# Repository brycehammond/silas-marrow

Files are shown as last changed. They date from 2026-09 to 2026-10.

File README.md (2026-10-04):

# Silas Marrow: the talking skull of the Elephant Corral

A life-size skull by the office door that turns to look at people, roasts their outfit in a raspy Old West voice, and talks back when they answer. The character is the (fictional) ghost of a faro dealer who has haunted the Elephant Corral at 1444 Wazee St since 1859. The history it uses is real, pulled from the building's historical markers.

```
 Anker C200 (in the base)
      │  video + mic
      ▼
 Mac mini ── skull.py ─────────────────────────────────────────────┐
   • YOLO pose tracking: where is the nearest face?                │
   • Claude (Sonnet 5.5): look at the frame, write a line           │
   • ElevenLabs Flash TTS: speak it; audio level drives the jaw     │
   • ElevenLabs Scribe STT: hear the reply, keep the conversation   │
   • Phone control page on port 8090                                │
      │ headphone jack                 │ USB serial                  │
      ▼                                ▼                             │
 PAM8403 amp ─► 40 mm speaker     Arduino Uno ─► jaw servo (MG90S)    │
 (under the jaw)                               ─► pan servo (MG996R)  │
                                               ─► tilt servo (MG996R) │
                                               ─► 2 x WS2812 eye jewels
```

## Folder map

| Path | What it is |
|---|---|
| `software/skull.py` | Main program: vision, behavior, web control page |
| `software/brain.py` | Claude prompts (greeting, conversation) |
| `software/voice.py` | ElevenLabs speech out with jaw sync, speech in |
| `software/vision.py` | Camera thread, YOLO pose tracking, gaze math |
| `software/faces.py` | Short-term face memory, so nobody is greeted twice |
| `software/hardware.py` | Serial link to the Arduino |
| `software/virtual.py` | Software twin of the Arduino sketch, for the on-screen skull |
| `software/web/` | The on-screen 3D skull (three.js) |
| `software/calibrate.py` | Servo, eye, mic and voice test tools |
| `software/persona.md` | Silas's character, history and rules. Edit freely. |
| `software/config.json` | All the tuning knobs |
| `firmware/skull_controller/` | Arduino sketch |
| `cad/skull_parts.scad` | Parametric source for every printed part |
| `cad/stl/` | Ready-to-print STLs (default measurements) |
| `cad/previews/` | Renders of the assembly and parts |
| `docs/parts.md` | Full parts list with quantities and specs |
| `docs/wiring.svg` | Wiring diagram |
| `docs/assembly.md` | Step-by-step assembly guide with a screw table |

## 1. Parts

The full list with quantities and specs is in [docs/parts.md](docs/parts.md). In short:

**Already in your cart:** Evotech skull, Hosyond MG996R 4-pack, Miuzei MG90S 4-pack, HiLetgo PAM8403 amp (with knob), Gikfun 40 mm 4Ω speakers, capacitor kit, lazy susan bearings, servo extension cables, ALITOVE 5V 5A supply, WS2812 7-LED jewels, speaker grille cloth.

**You have:** Mac mini, Anker PowerConf C200, Arduino Uno (a Nano works too), 3D printer.

**Small hardware to scrounge or grab at the hardware store:**

- M3 screws, 8 to 16 mm, about 30 (they self-tap into the printed pilot holes)
- One M5 x 50 mm bolt, nylon lock nut and 2 washers (idle tilt pivot)
- 1.5 mm steel wire for the jaw pushrod (music wire, or a big paperclip)
- 5-minute epoxy or E6000 (jaw tab, eye holders)
- Double-sided foam tape, small zip ties, hookup wire
- One 330Ω resistor (eye data line)
- A 5V USB wall charger and a spare USB cable to cut up (amp power)
- A 3.5 mm audio cable to cut up (Mac headphone jack to amp)

## 2. Printing

Default measurements match the parts you ordered. **Before printing, measure your actual parts** and edit the values marked `(M)` at the top of `cad/skull_parts.scad`. Then re-export with:

```bash
brew install --cask openscad@snapshot    # the stable cask is disabled in Homebrew
openscad -D 'part="turntable"' -o stl/turntable.stl skull_parts.scad
```

| Part | Qty | Material | Orientation / supports | Notes |
|---|---|---|---|---|
| `base_shell` | 1 | PLA, 3 walls, 15% infill | Top face on the bed (the STL is already flipped). No supports. | About 12 hr. Needs a 150 mm square bed area. |
| `base_floor` | 1 | PLA | Flat | Arduino standoffs, amp pad, camera cradle screws |
| `camera_cradle` | 1 | PLA | As exported, **supports on** under the shelf | Check `cam_w/h/d` against your Anker first |
| `grille_frame` | 1 | PLA, black | Lip on the bed | Clamps the grille cloth in the camera window |
| `turntable` | 1 | PETG preferred, 40% infill | Disc on the bed | Carries the whole head. Check `ls_size`, `ls_hole`. |
| `horn_column` | 1 | PETG | Standing up | Couples the pan servo horn to the turntable. Flat sides leave room for the wires. |
| `cradle` | 1 | PETG, 40% infill | Platform on the bed (already flipped) | The skull sits on this. Jaw servo mounts to it. |
| `pivot_spacer` | 1 | Any | Standing up | Goes on the M5 bolt |
| `speaker_holder` | 1 | PLA | Ring on the bed | |
| `jaw_tab` | 2 | PLA | Flat | One spare |
| `eye_holder` | 2 | PLA, black | Flat | |
| `eye_diffuser` | 2 | White or translucent PLA/PETG, 2 perimeters | Dome up | Frosts the LEDs into a glow |
| `pvc_socket` | 1 | PLA | Flange on the bed | Optional: mounts the base on a 2" PVC pipe column |

**Print order.** Start with the small parts that test your measurements, and leave the 12-hour `base_shell` for last:

1. `camera_cradle`, `speaker_holder` and both `eye_holder`s. They are quick, and each one checks a measured part (the camera, the speaker, the LED jewel). Fix the `(M)` values and re-export if anything is off.
2. Both `jaw_tab`s and both `eye_diffuser`s. With the eye holders, that is everything you need to prepare the skull, and the jaw tab's epoxy can cure while the big parts print.
3. `base_floor`. Check the camera cradle screw holes and the Arduino standoffs against it.
4. `grille_frame` and `pivot_spacer`, whenever they fit in. Batch the frame with the eye holders if you are swapping to black filament.
5. `base_shell`. It depends on the servo and lazy susan measurements too (the pan servo mount and the bearing slots), so check those once more before you commit to it.

The PETG neck parts (`turntable`, `horn_column`, `cradle`) are a separate batch. The neck cannot be assembled until they and the shell are done.

## 3. Wiring

Wiring diagram

The same connections as text:

```
                   ALITOVE 5V 5A ── screw adapter ──┬── + servo power rail
                                                    └── − servo power rail ─┐
  1000µF cap across + and − right at the rail (stripe to −)                 │
                                                                            │
  Arduino Uno                                                               │
    D9  ── jaw servo signal (orange)       servo red  ── + rail             │
    D10 ── pan servo signal                servo brown ── − rail            │
    D11 ── tilt servo signal                                                │
    D6  ──[330Ω]── eye jewel #1 DIN;  jewel #1 DOUT ── jewel #2 DIN          │
               jewels 5V ── + rail;  jewels GND ── − rail                   │
    GND ───────────────────────────────────────────────────────────────────┘
    USB ── Mac mini (data + Arduino power)

  Audio:  Mac mini headphone jack ── 3.5 mm cable ── PAM8403 L-in + GND
          PAM8403 L-out +/− ── 40 mm speaker     (never tie L− and R− together)
          PAM8403 5V/GND ── separate USB wall charger (keeps servo noise out)
          Put a 1000µF cap across the amp's 5V/GND pads.
```

Rules that prevent 90% of problems:

- **Common ground.** Arduino GND must connect to the servo supply's −. Otherwise the servos twitch randomly.
- **Never power servos from the Arduino's 5V pin.** The ALITOVE powers servos and eyes.
- **Keep the amp on its own USB charger.** Sharing the servo supply puts buzz in the voice.
- Run the skull's wires (jaw servo, eyes, speaker) down through the foramen magnum (the big hole in the skull base), through the cradle's center hole, the turntable's two cable openings beside the horn column, the lazy susan, and into the base. Leave a loose loop so the head can turn ±60°.

## 4. Assembly

The full guide, with a screw table, pictures and a bench test to do first, is in
[docs/assembly.md](docs/assembly.md). The short version:

**Skull prep**

1. Lift off the skull cap (it's held with magnets and pegs, so pull straight up).
2. Unhook the jaw spring. The servo drives the jaw now. If the jaw flops too freely, a much lighter rubber band can take the spring's place later.
3. Epoxy the `jaw_tab` to the inside of the chin, centered, with the ear pointing back toward the throat.
4. Press each LED jewel into an `eye_holder`, clip a `eye_diffuser` on the front, and epoxy the holders inside the eye sockets from within the cranium. Chain the jewels (DOUT of the first to DIN of the second) and route the three wires down through the foramen magnum.
5. Weather the skull if you like: raw umber acrylic, brushed on and wiped off, leaves "old bone" in the cracks.

**Neck**

6. Trim two opposite sides off the pan servo's round disc horn so it is 17 mm wide, the same as the flat-sided `horn_column`. Screw the horn to the bottom of the column with the flats lined up (radial slots fit most horns), then screw the column under the `turntable` with four countersunk M3s. The wires from the head pass down beside those flats.
7. Screw the lazy susan's top plate to the turntable, and its bottom plate to the top of the `base_shell` (the diagonal slots fit most hole patterns).
8. Hang the pan servo under the base top: shaft up into the horn, tabs screwed to the two bridges. Before pressing it onto the horn, center the servo (`python calibrate.py servos`, pick 1, press c) with the head facing forward.
9. Mount the tilt servo in the +X upright with its body outside and the spline poking through.
10. Mount the MG90S jaw servo in the cradle's front plate, and the speaker in the `speaker_holder`, screwed to the cradle's front edge.
11. Screw the `cradle` to the skull base with M3s through the long slots. **Don't tighten yet.**
12. Hang the cradle in the yoke: servo horn screwed to the +X arm, M5 bolt through the −X upright, spacer and arm.
13. **Balance.** With the tilt servo relaxed (`X` command or unplugged), slide the skull forward or back in the slots until it barely tips either way. Then tighten. A balanced head is what lets the MG996R hold it steadily all day.
14. Bend a Z in one end of the 1.5 mm wire, hook it in the jaw tab, and connect the other end to the jaw servo horn. With the servo at closed, size the wire so the jaw is just shut.

**Base**

15. Screw the Arduino to the standoffs on the `base_floor`, stick the amp on its pad with foam tape, and screw the `camera_cradle` in behind the window.
16. Strap the Anker into the cradle with zip ties. Its lens should sit right against the window.
17. Stretch grille cloth over the window and press the `grille_frame` in from outside to clamp it tight.
18. Screw the floor to the shell. Optional: bolt on the `pvc_socket` and stand the whole thing on a 2" PVC pipe so the skull is at eye level.

## 5. Mac mini setup

```bash
brew install python@3.12 ffmpeg
cd talking-skull/software
python3.12 -m venv .venv && source .venv/bin/activate
pip install -r requirements.txt
cp .env.example .env        # paste your Anthropic and ElevenLabs keys in
```

**Voice.** `config.json` uses **Jessie, Vintage Narrator** (`KgUSWQPFmuiZ5ycRbnty`), a raspy Wild West old-timer from the ElevenLabs voice library. Library voices need to be added to your account before the API can use them: in ElevenLabs, open Voice Library, search "Jessie Vintage Narrator", and click Add to my voices. Two other good fits:

- `uVKHymY7OYMd6OailpG5`: Frederick, Old Gnarly Narrator (deep, grizzled)
- `1BfrkuYXmEwp8AWqSLWk`: Declan Graves (creepier, slight Irish rasp)

**Devices.**

```bash
python skull.py --list-cameras     # set camera.index
python skull.py --list-audio       # set voice.output_device and ears.input_device (name fragments)
ls /dev/cu.usbmodem*               # set hardware.serial_port
```

Give Terminal camera and microphone access when macOS asks (System Settings > Privacy & Security).

**Firmware.** In the Arduino IDE, install **Adafruit NeoPixel** from the Library Manager, open `firmware/skull_controller/skull_controller.ino`, and upload to the Uno.

## 6. Calibration

1. **Servo limits.** Take the skull off first. Run `python calibrate.py servos`. For each servo, find the pulse for jaw closed and open, pan center and a comfortable left limit, and tilt level and a comfortable up limit. Put the numbers in the calibration block at the top of the sketch and upload again. Flip the sign of `PAN_SPAN_US` or `TILT_SPAN_US` if an axis runs backwards.
2. **Eyes.** `python calibrate.py eyes` cycles colors and modes. Pick a color on the phone page later.
3. **Voice and jaw.** `python calibrate.py say "Howdy, pilgrim."`. If the jaw flaps at silence, raise `jaw_floor_db`. If it barely moves, lower `jaw_ceiling_db`. If it runs ahead of or behind the audio, adjust `jaw_delay_s` by ±0.05.
4. **Mic.** `python calibrate.py mic`. Talk from where people stand and set `ears.speech_min_rms` a bit above the room-noise reading.
5. **Gaze.** `python skull.py --show`, stand in front, and move around. If the head aims low (the camera sits below the eyes), raise `gaze.tilt_offset_deg`. If it turns the wrong way, set `invert_pan` or `invert_tilt`. If it under- or over-turns, adjust `pan_range_deg` and `tilt_range_deg` to match the angles your servo spans reach.

## 7. Running it

```bash
python skull.py --show --no-skull    # first test: camera + Claude + voice, no Arduino
python skull.py --show               # everything, with a preview window
python skull.py                      # headless; use the phone page
```

Open `http://<mac-mini-name>.local:8090` on your phone. The page has:

- a live camera view
- **Arm** (it starts armed; set `start_armed` to `false` in `config.json` to change that) and **Conversation** toggles
- **Greet now**, **Stop talking**, **Center head** and **Relax servos** buttons
- a **Say** box, so you can puppet Silas live
- volume and eye color controls
- a log of everything it said and heard

Set `web.token` to require `?t=yourtoken` on the URL.

### Virtual skull

No hardware on the desk? Silas can live on the screen instead:

```bash
python skull.py --virtual                        # everything, with an on-screen skull
python skull.py --virtual --no-voice --no-ai     # no API keys needed
```

`--virtual` replaces the Arduino with a 3D skull in its own window. Everything else is
the real thing: it watches through this computer's camera, listens on its microphone,
talks through its speakers, and greets and converses by the same rules. It starts armed,
and you can disarm it from the control page as usual.

- **Devices.** With `--virtual`, the `camera`, `ears`, `voice` and `gaze` values inside
  the `virtual` section of `config.json` replace the main ones. `null` for a device means
  the system default, which is normally the built-in microphone and speakers. The Mac
  mini settings are left alone. The virtual camera is picked by name
  (`virtual.camera.name`, "MacBook Pro Camera"), because an iPhone nearby can take
  index 0. `--list-cameras` shows each camera's index and name. Change the name if your
  Mac's camera is called something else. With no match it falls back to `index`.
- **Permissions.** macOS asks for Camera and Microphone access for the terminal you
  run it from.
- **Window.** It opens in Google Chrome's app mode if Chrome is installed, otherwise in
  your default browser. Set `virtual.open_window` to `false` to open it yourself at
  `http://localhost:8090/skull`. Keys: **F** full screen, **C** camera picture,
  **H** hide the text.
- **Gaze.** A webcam sits above the screen, not under the skull. If Silas looks over your
  head or at your chest, change `virtual.gaze.tilt_offset_deg`. If he turns the wrong way
  (a mirrored camera), set `virtual.invert_pan`.
- **Same behavior as the hardware.** The on-screen skull obeys the same commands as the
  Arduino, with the same head smoothing, jaw timeout and eye modes. It also runs next to
  the real skull: open `/skull` on any device to watch a live twin.
- **Without a voice** (`--no-voice`) the jaw still moves for each line, so you can see
  him talk.
- **A better looking skull.** The built-in skull is generated by code and is stylized.
  To use a sculpted one, save it as `software/web/skull.glb` with these named parts:
  `cranium`, `jaw` (its origin on the jaw hinge), and empties `eye_L` and `eye_R` in the
  sockets. Face it toward +Z with Y up, with the jaw's local X axis along the hinge
  (in Blender: face it toward -Y, leave the jaw unrotated, and export glTF with +Y up).
  Any size works. Restart `skull.py` after adding the file.

**How it behaves.** When an armed skull sees a face close enough (`min_height_frac`) for `present_s`, it greets that person once and waits at least `min_gap_s` between greetings. It remembers each face it has greeted and leaves that person alone for 4 hours (`regreet_same_person_after_s`), even if they leave and come back. The exception: someone already greeted who stops and looks at it for 10 seconds (`linger_s`) gets another line, at most once every 5 minutes (`linger_gap_s`). It needs about a second of clear, front-on view before it greets, so it can tell who it is looking at. Set `greet_unrecognized` to `true` to greet people whose face it can't make out, or `recognize_faces` to `false` to go back to tracking alone. With conversation on, it listens for up to 5 seconds after each line and keeps talking for up to 4 turns, or until the person walks away. It only runs during `active_hours` (7am to 7pm by default), and `ambient_every_min` can make it mutter to itself when the hall is empty (off by default).

**Keep it running.** Use `caffeinate -dimsu &`, or a launchd job like the one in the spider README.

**Costs (rough).** A greeting sends one downscaled frame plus the persona to Claude Sonnet 5.5: about 2,000 input tokens. On Haiku 4.5 that came to around $0.25 for 100 greetings a day. Sonnet costs more, so check Anthropic's current pricing. ElevenLabs is the bigger cost. Each line is about 100 to 150 characters, and Flash models bill around half a credit per character, so check that your plan's monthly credits cover a busy month. `max_greetings_per_hour` is your cost cap.

## 8. Make it yours

- **Personality and history:** edit `software/persona.md`. It is plain text, and the program re-reads it on start.
- **Cheaper replies:** set `claude.model` to `claude-haiku-4-5-20251001` and delete the `claude.thinking` line. Haiku rejects that setting. Sonnet 5.5 needs it: without `"thinking": "between_tools"` it spends the whole token budget thinking and returns an empty line.
- **More expressive voice:** set `voice.tts_model` to `eleven_v3` and `claude.allow_audio_tags` to `true`. Silas can then `[chuckles]` and `[whispers]`, at the cost of more latency.

## 9. Privacy and etiquette

Camera frames are sent to Anthropic's API only at the moment of a greeting. Speech is sent to ElevenLabs only while the skull is listening. Nothing is saved to disk. The persona forbids comments on bodies, age, race and the like, and it has to admit it's an AI if someone sincerely asks.

## 10. Troubleshooting

| Symptom | Fix |
|---|---|
| Servos twitch or the Arduino resets | Common ground missing, supply too weak, or the 1000µF cap is missing |
| Head drifts to center on its own | The Mac stopped sending (watchdog). Check the serial port. |
| Jaw doesn't move while talking | `jaw_floor_db` is too high, or the pushrod is binding. Test with `calibrate.py say`. |
| Voice buzzes or hums | Amp on its own USB charger. Add the cap. Try a ground loop isolator. |
| `ElevenLabs TTS 401/403` | The key is wrong, or the voice isn't added to your account |
| PCM refused | The code falls back to MP3 automatically (needs `brew install ffmpeg`) |
| It greets the same person over and over | Lower `face_match_threshold` a little (0.30) so faces match more easily, and raise `linger_gap_s` |
| It ignores a new person | Raise `face_match_threshold` (0.45). It may be taking them for someone it already greeted. |
| It never greets | Check that it's armed, inside active hours, and that `min_height_frac` isn't too high for your hallway. It also waits for a clear, front-on face unless `greet_unrecognized` is `true`. |
| Virtual skull page says "offline" | `skull.py` is not running, or the `?t=` token is missing from the URL |
| Virtual skull hears nothing | Microphone access for the terminal, and `virtual.ears.input_device` (`null` = system default) |

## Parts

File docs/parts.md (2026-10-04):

# Parts list

Everything needed to build the physical skull. Wiring is in [wiring.svg](wiring.svg),
assembly is in [assembly.md](assembly.md), and print settings are in the
[README](../README.md).

Brands are the ones used in this build. Any part that matches the spec will work, but
check the printed parts against it first: the dimensions marked `(M)` in
`cad/skull_parts.scad` were measured from these exact parts. Prices and shop links are
left out because they go stale.

The on-screen skull (`python skull.py --virtual`) needs none of this, only a Mac with a
camera and a microphone.

## Electronics

| Part | Qty | Spec | Used in this build | Job |
|---|---|---|---|---|
| Arduino Uno | 1 | A Nano also works | | Drives the servos and eyes |
| Standard servo | 2 | MG996R, metal gear | Hosyond, sold as a 4-pack | Pan and tilt |
| Micro servo | 1 | MG90S, metal gear | Miuzei, sold as a 4-pack | Jaw |
| LED jewel | 2 | WS2812, 7 LEDs, 23 mm across | | Eyes |
| Power supply | 1 | 5 V, 5 A, with a barrel to screw terminal adapter | ALITOVE | Servos and eyes |
| Electrolytic capacitor | 2 | 1000 µF, rated 10 V or more | From a capacitor kit | One across the servo power rail, one across the amp's power pads |
| Resistor | 1 | 330 Ω | | In series with the eye data line |
| Amplifier board | 1 | PAM8403, with volume knob | HiLetgo | Drives the speaker |
| Speaker | 1 | 40 mm, 4 Ω | Gikfun | Voice, mounted under the jaw |
| Servo extension cable | up to 3 | One per servo that cannot reach the Arduino | | Runs from the head down into the base |
| USB wall charger | 1 | 5 V | | Powers the amp only |
| USB cable | 1 | Any spare one, to cut up | | Charger to amp |
| Audio cable | 1 | 3.5 mm, to cut up | | Headphone jack to amp |
| USB cable for the Arduino | 1 | Type B for an Uno | | Arduino to computer |
| Hookup wire | some | | | Power rail, eyes, speaker |

The 10 V rating on the capacitors is a recommendation added here. The README only gives
the capacitance.

## Computer, camera and microphone

| Part | Qty | Used in this build | Job |
|---|---|---|---|
| Computer | 1 | Mac mini | Runs `skull.py` |
| Webcam with microphone | 1 | Anker PowerConf C200, 40.8 x 50.6 x 55.1 mm with the clip folded | Sees and hears visitors |

## Mechanical

| Part | Qty | Spec | Job |
|---|---|---|---|
| Life-size plastic skull | 1 | Hinged jaw, removable cap. This build uses an Evotech skull. | Silas |
| Lazy susan bearing | 1 | Sold as 3 in. The plates measure 72 mm square, 9 mm tall, with a 35.3 mm center opening. | Carries the head on the base |
| M3 screws | about 30 | 8 to 16 mm long | Self-tap into the printed pilot holes |
| M5 bolt | 1 | 50 mm long | Idle tilt pivot |
| M5 nylon lock nut | 1 | | Idle tilt pivot |
| M5 washer | 2 | | Idle tilt pivot |
| Machine screws with nuts and washers | about 8 | Short, M3 or M4 to suit the bearing's holes | Lazy susan plates to the turntable and base. Not in the README. See the assembly guide. |
| Steel wire | 1 short length | 1.5 mm music wire, or a large paperclip | Jaw pushrod |
| Speaker grille cloth | 1 piece | Big enough to cover the camera window | Hides the camera |
| PVC pipe | 1, optional | 2 in | Stands the skull at eye level |

## Printed parts

Material, orientation and supports are in section 2 of the README.

| Part | Qty | Material |
|---|---|---|
| `base_shell` | 1 | PLA |
| `base_floor` | 1 | PLA |
| `camera_cradle` | 1 | PLA |
| `grille_frame` | 1 | PLA, black |
| `turntable` | 1 | PETG preferred |
| `horn_column` | 1 | PETG |
| `cradle` | 1 | PETG |
| `pivot_spacer` | 1 | Any |
| `speaker_holder` | 1 | PLA |
| `jaw_tab` | 2 | PLA. One is a spare. |
| `eye_holder` | 2 | PLA, black |
| `eye_diffuser` | 2 | White or translucent PLA or PETG |
| `pvc_socket` | 1, optional | PLA |

## Consumables

| Item | Job |
|---|---|
| 5-minute epoxy or E6000 | Jaw tab and eye holders |
| Double-sided foam tape | Holds the amp on its pad |
| Small zip ties | Straps the camera into its cradle |
| Raw umber acrylic paint, optional | Weathers the skull |

## Tools

| Tool | Why |
|---|---|
| 3D printer | Needs a 150 mm square bed area for `base_shell` |
| Soldering iron | The LED jewels have solder pads, and the cut audio and USB cables need joining |
| Arduino IDE | Uploads the firmware. Needs the Adafruit NeoPixel library. |

## What is left over

The servos are sold in packs of four. This build uses two MG996R and one MG90S, which
leaves two and three spare.

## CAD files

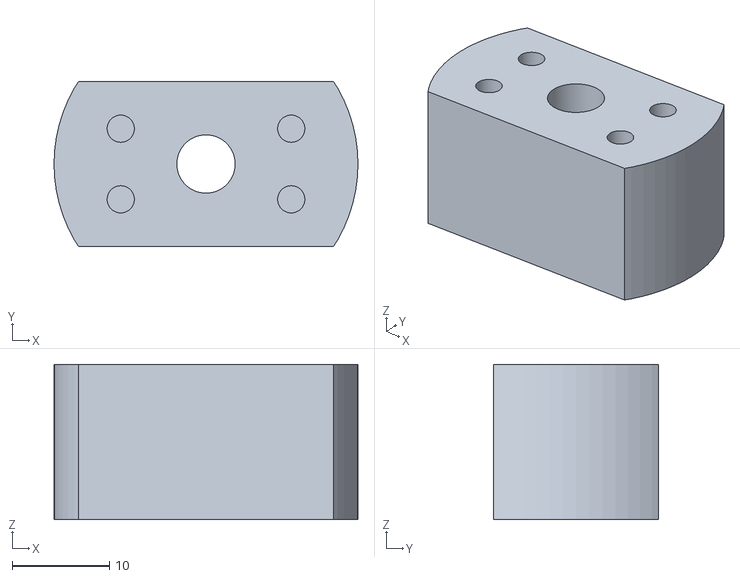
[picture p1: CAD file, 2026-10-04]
cad/stl/horn_column.stl
31.3 x 17.0 x 16.0

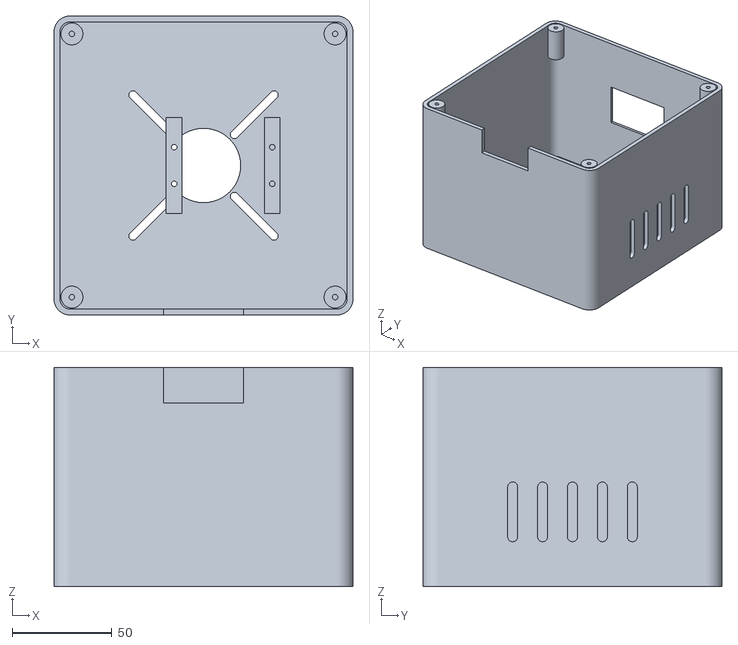
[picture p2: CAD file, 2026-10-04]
cad/stl/base_shell.stl
150.0 x 150.0 x 110.0

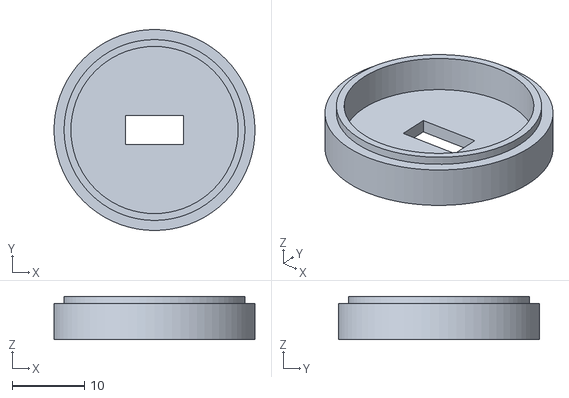
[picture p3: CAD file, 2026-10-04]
cad/stl/eye_holder.stl
27.9 x 27.9 x 6.00

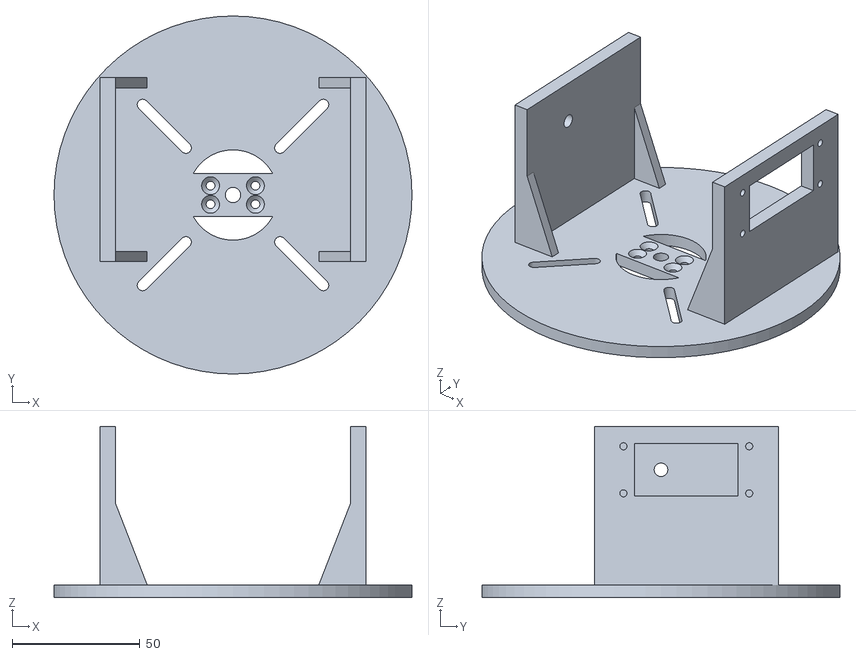
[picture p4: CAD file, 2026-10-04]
cad/stl/turntable.stl
140.0 x 140.0 x 67.0

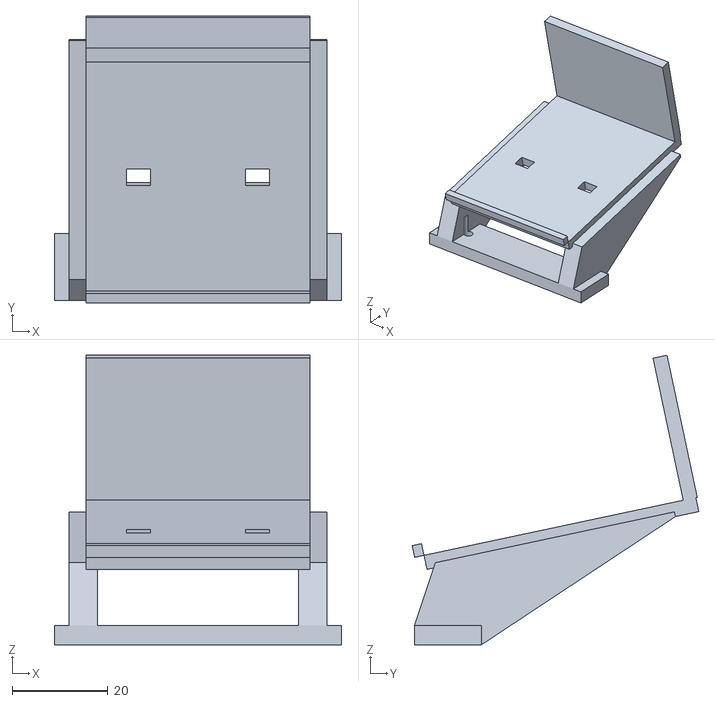
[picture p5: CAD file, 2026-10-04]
cad/stl/camera_cradle.stl
60.0 x 59.9 x 60.5

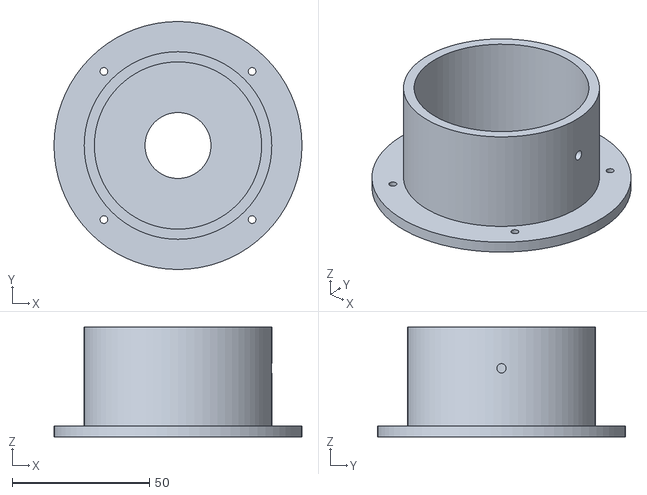
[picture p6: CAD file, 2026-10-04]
cad/stl/pvc_socket.stl
90.3 x 90.3 x 40.0

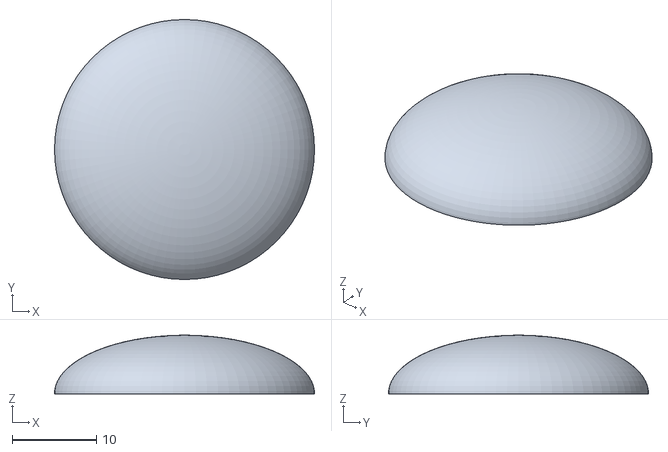
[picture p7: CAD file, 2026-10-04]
cad/stl/eye_diffuser.stl
30.9 x 30.9 x 6.95

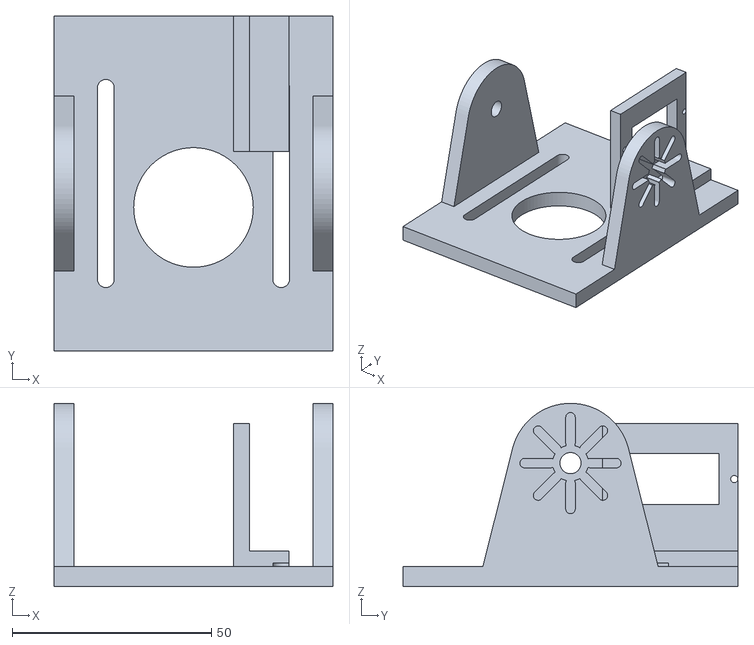
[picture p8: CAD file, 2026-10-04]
cad/stl/cradle.stl
70.0 x 84.0 x 46.0

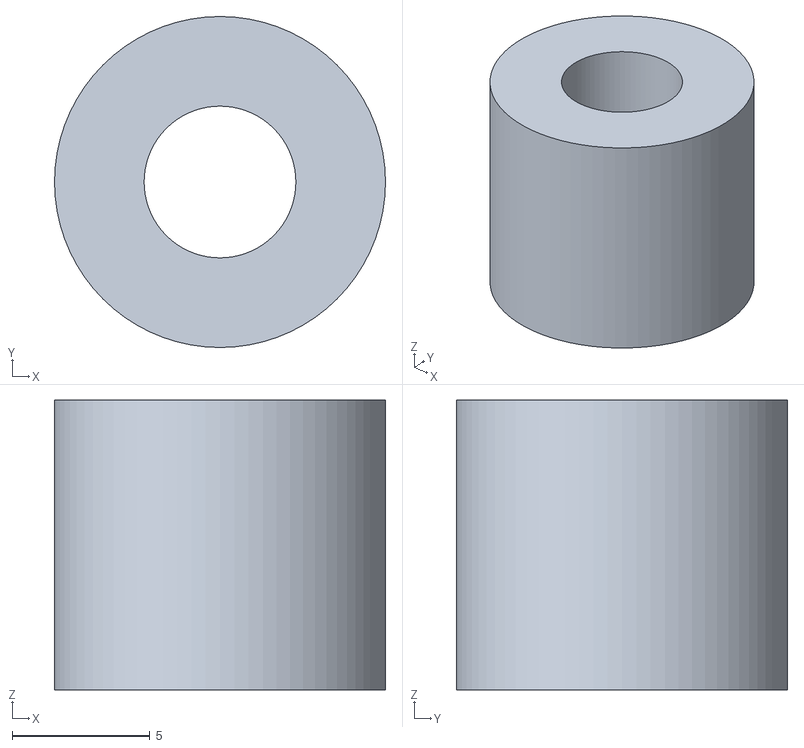
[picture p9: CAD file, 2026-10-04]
cad/stl/pivot_spacer.stl
12.0 x 12.0 x 10.5

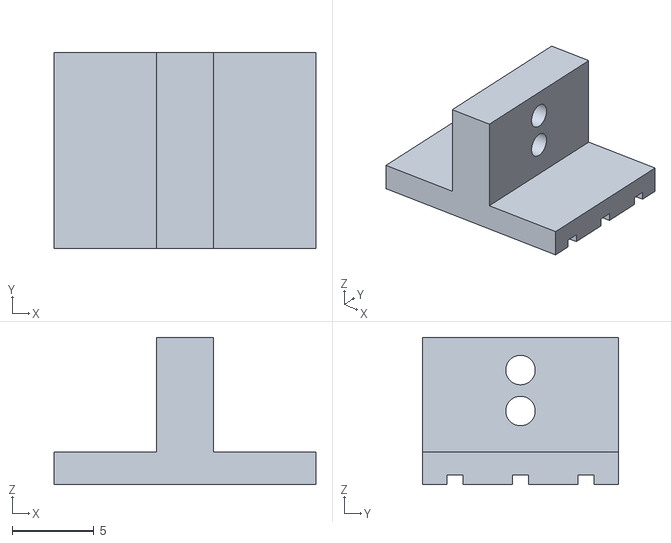
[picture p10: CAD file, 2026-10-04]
cad/stl/jaw_tab.stl
16.0 x 12.0 x 9.00

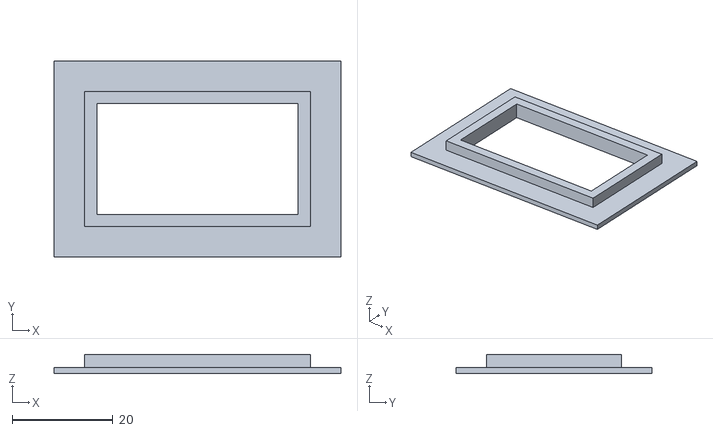
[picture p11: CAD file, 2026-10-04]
cad/stl/grille_frame.stl
57.0 x 39.0 x 3.79

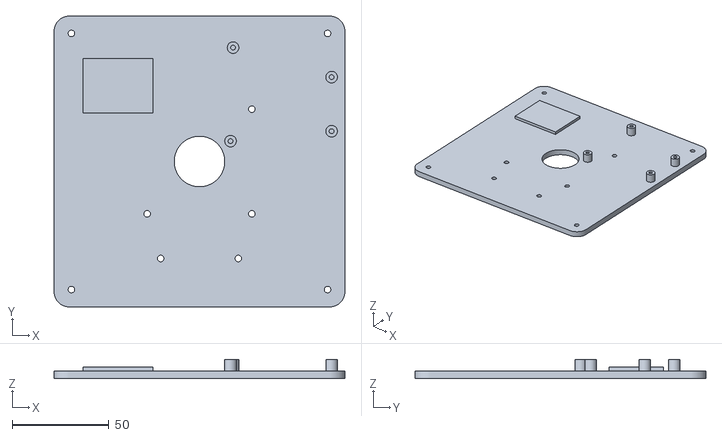
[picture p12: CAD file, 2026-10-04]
cad/stl/base_floor.stl
150.0 x 150.0 x 10.0

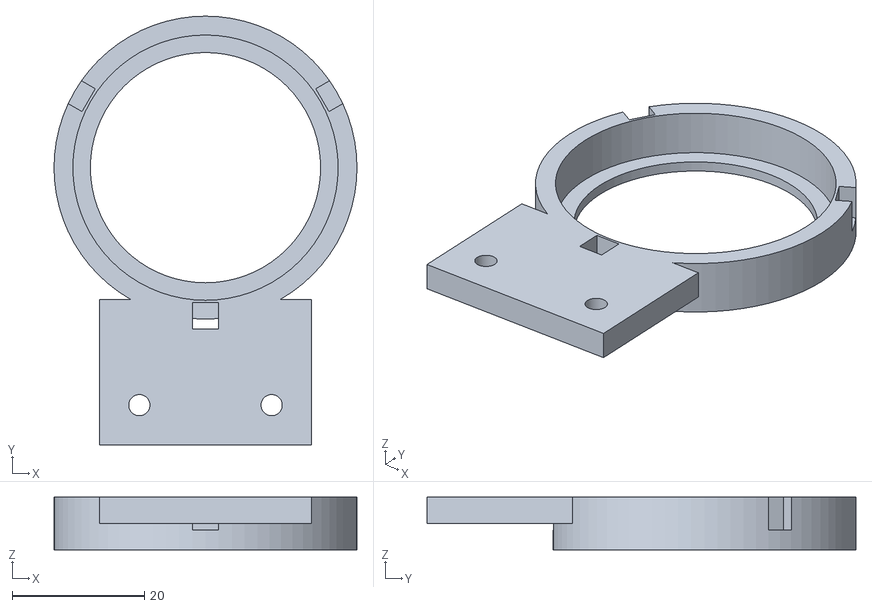
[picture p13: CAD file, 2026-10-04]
cad/stl/speaker_holder.stl
45.8 x 64.8 x 8.00

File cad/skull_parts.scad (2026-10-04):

// ===========================================================================
// Talking skull: printable parts (parametric OpenSCAD)
//
// Render one part:   openscad -D 'part="turntable"' -o turntable.stl skull_parts.scad
// Preview assembly:  open this file in OpenSCAD with part="assembly"
//
// MEASURE YOUR PARTS and edit the values marked (M) before printing.
// Units: millimeters. Front of the prop is -Y (toward the people).
// ===========================================================================

part = "assembly";   // see the list at the bottom of this file
$fn = 72;
eps = 0.01;
tol = 0.3;           // general printing clearance

// ---------------- base (pedestal) ----------------
base_w = 150;  base_d = 150;  base_h = 110;
wall = 3;      top_t = 5;     corner_r = 8;
floor_t = 4;

// ---------------- lazy susan (sold as 3 in, plates measure 72 mm) ----------------
ls_size = 72;      // (M) plate size
ls_h = 9;            // (M) total height of the bearing, plate to plate
ls_hole = 35.3;        // (M) diameter of the lazy susan's center opening
ls_slot_r0 = 22;     // slots along the diagonals from r0 to r1 fit most hole patterns
ls_slot_r1 = 50;

// ---------------- MG996R (neck servos) ----------------
s_L = 40;          // (M) body length
s_W = 20;          // (M) body width
s_tab_under = 32.2;  // (M) bottom of case to underside of the mounting tabs
s_tab_t = 2.4;
s_spline_top = 46.4; // (M) bottom of case to top of output spline
s_shaft_off = 10.1;  // (M) end of case to shaft center
s_hole_L = 49.2;     // (M) tab hole spacing along length
s_hole_W = 18.4;       // (M) tab hole spacing across width
s_pilot = 2.8;       // self-tapping M3 into plastic
horn_d = 20.5;         // (M) round disc horn diameter
horn_t = 2.3;          // (M) horn disc thickness above the spline

// ---------------- MG90S (jaw servo) ----------------
j_L = 22.7;  j_W = 12.2;  j_tab_under = 17.8;  j_tab_t = 2.5;
j_spline_top = 32.4;  j_shaft_off = 6.0;  j_hole_L = 30.9;  j_pilot = 1.8;

// ---------------- neck geometry ----------------
tt_d = 140;          // turntable disc diameter
tt_t = 5;
column_d = ls_hole - 4;
column_w = 17;       // the column is flattened to this width so the cables pass either side
col_screw_a = [22.5, 157.5, 202.5, 337.5];   // column screws: between the horn slots
pivot_h = 45;        // tilt axis height above the turntable top
up_t = 6;            // upright thickness
up_w = 72;           // upright width (along Y), offset to cover the servo tabs
cr_w = 70;           // cradle platform width (X)
cr_d = 84;           // cradle platform depth (Y)
cr_t = 5;
arm_t = 5;
arm_drop = 26;       // platform underside to pivot axis
horn_gap = 11;       // upright inner face to cradle arm (fits spline + horn)
pivot_bolt = 5.3;    // M5 bolt for the idle side

// ---------------- camera + window ----------------
cam_w = 40.8;          // (M) Anker C200 width
cam_h = 50.6;          // (M) height
cam_d = 55.1;          // (M) depth front to back, clip folded
cam_tilt = 12;       // degrees upward
win_w = 46;  win_h = 28;
win_z = 48;          // window center height above the bottom of the base

// ---------------- electronics ----------------
uno_holes = [[14, 2.5], [15.3, 50.7], [66.1, 7.6], [66.1, 35.5]];
pvc_od = 60.3;       // 2 in schedule 40 PVC pipe

// ===========================================================================
// helpers
// ===========================================================================
module rbox(w, d, h, r) {
    hull() for (x = [-w/2 + r, w/2 - r], y = [-d/2 + r, d/2 - r])
        translate([x, y, 0]) cylinder(r = r, h = h);
}

module slot(len, w, h) {   // along +X from origin
    hull() { cylinder(d = w, h = h); translate([len, 0, 0]) cylinder(d = w, h = h); }
}

module diag_slots(r0, r1, w, h) {
    for (a = [45, 135, 225, 315]) rotate(a) translate([r0, 0, 0]) slot(r1 - r0, w, h);
}

module horn_slots(h, angles = [0 : 45 : 315], len = 6.5) {   // radial slots that fit most disc horns
    for (a = angles) rotate(a) translate([5, 0, 0]) slot(len, 2.4, h);
}

// Footprint shared by the horn column and the middle of the turntable: a round
// column with two flats. The wires from the head run down past the flats,
// inside the lazy susan's center opening.
module column_profile(h) {
    intersection() {
        cylinder(d = column_d, h = h);
        translate([-column_d/2, -column_w/2, 0]) cube([column_d, column_w, h]);
    }
}

module cable_channels(h) {   // the two openings either side of the column
    difference() {
        cylinder(d = ls_hole, h = h);
        translate([-ls_hole/2 - 1, -column_w/2, -1]) cube([ls_hole + 2, column_w, h + 2]);
    }
}

// ===========================================================================
// 1. base shell: hollow pedestal. Print upside down (top face on the bed).
// ===========================================================================
z_hc = base_h - top_t - 2;               // horn disc top under the top plate
s_spline_z = z_hc - horn_t;
s_tab_top_z = s_spline_z - (s_spline_top - s_tab_under - s_tab_t);
s_center_x = s_L/2 - s_shaft_off;        // servo body center relative to shaft

module base_shell() {
    difference() {
        union() {
            difference() {
                rbox(base_w, base_d, base_h, corner_r);
                translate([0, 0, -eps]) rbox(base_w - 2*wall, base_d - 2*wall,
                                             base_h - top_t, corner_r - wall);
            }
            // corner bosses for the floor screws
            for (x = [-1, 1], y = [-1, 1])
                translate([x * (base_w/2 - 9), y * (base_d/2 - 9), 0])
                    cylinder(d = 11, h = 22);
            // pan servo bridges: bars under the tab holes, legs out past the horn
            for (hx = [s_center_x - s_hole_L/2, s_center_x + s_hole_L/2]) {
                translate([hx - 4, -24, s_tab_top_z]) cube([8, 48, 5]);
                for (y = [-24, 18])
                    translate([hx - 4, y, s_tab_top_z]) cube([8, 6, base_h - top_t - s_tab_top_z + eps]);
            }
        }
        // floor screw pilots
        for (x = [-1, 1], y = [-1, 1])
            translate([x * (base_w/2 - 9), y * (base_d/2 - 9), -eps]) cylinder(d = s_pilot, h = 18);
        // servo tab pilots (drilled up into the bridges)
        for (hx = [s_center_x - s_hole_L/2, s_center_x + s_hole_L/2], y = [-s_hole_W/2, s_hole_W/2])
            translate([hx, y, s_tab_top_z - eps]) cylinder(d = s_pilot, h = 5 + 2*eps);
        // clearance for the servo body between the bridges
        translate([s_center_x - s_L/2 - tol, -s_W/2 - tol, s_tab_top_z - 1])
            cube([s_L + 2*tol, s_W + 2*tol, base_h - top_t - s_tab_top_z + 1 - eps]);
        // center opening for the turntable column
        translate([0, 0, base_h - top_t - 1]) cylinder(d = column_d + 6, h = top_t + 2);
        // lazy susan screw slots
        translate([0, 0, base_h - top_t - 1]) diag_slots(ls_slot_r0, ls_slot_r1, 4.2, top_t + 2);
        // camera window + recess for the grille frame lip
        translate([-win_w/2, -base_d/2 - 1, win_z - win_h/2]) cube([win_w, wall + 2, win_h]);
        translate([-(win_w + 12)/2, -base_d/2 - 1, win_z - (win_h + 12)/2])
            cube([win_w + 12, 1 + 1.2, win_h + 12]);
        // rear cable exit
        translate([-20, base_d/2 - wall - 1, -eps]) cube([40, wall + 2, 18]);
        // side vents
        for (s = [-1, 1], i = [0 : 4])
            translate([s * base_w/2 - wall, -30 + i * 15, 60]) rotate([0, 90, 0])
                translate([0, 0, -1]) hull() { cylinder(d = 5, h = wall + 2);
                    translate([-25, 0, 0]) cylinder(d = 5, h = wall + 2); }
    }
}

// ===========================================================================
// 2. base floor: screws under the shell, carries the Arduino, amp and camera.
// ===========================================================================
uno_origin = [2, 8];    // board corner position on the floor (rear right area)
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

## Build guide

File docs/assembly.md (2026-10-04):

# Assembly guide

How to put the physical skull together, from a pile of parts to a talking head.
Allow an afternoon once everything is printed.

- Parts and quantities: [parts.md](parts.md)
- Wiring: [wiring.svg](wiring.svg)
- Print settings, calibration and troubleshooting: [README](../README.md)

The steps follow the README. The screw sizes, hole counts and clearances were worked out
from the hole sizes in `cad/skull_parts.scad`. Nothing here has been checked against a
finished build yet, so read [Open questions](#open-questions) before you start.

If you printed the `turntable` or `horn_column` before the cable path was fixed, print
them again. The old ones have round cable holes and a fully round column, and the
wires cannot get through.

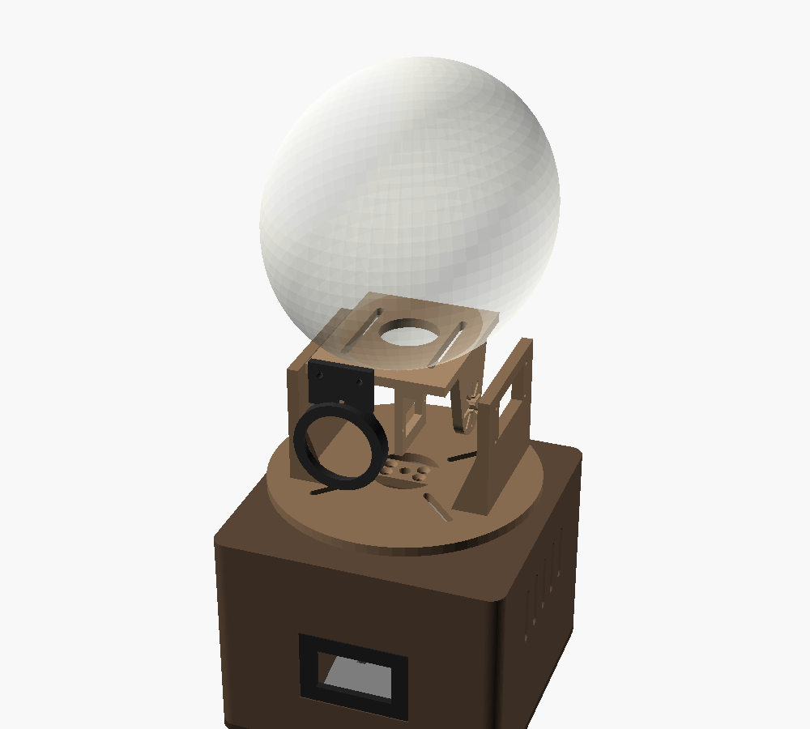
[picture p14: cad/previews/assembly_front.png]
The assembled neck and base


## Words used in this guide

| Word | Meaning |
|---|---|
| Front | The side of the base with the camera window. It faces the visitors. |
| Right upright | The turntable upright with the rectangular servo cutout. It is on your right when you face the front. The CAD calls it +X. |
| Left upright | The turntable upright with the single round bolt hole. The CAD calls it -X. |
| Horn | The plastic disc or arm that pushes onto a servo's output shaft. |

## Screws

All M3 screws self-tap into printed pilot holes. Drive them slowly and stop when they
are snug. A stripped hole in plastic does not recover.

| Where | Qty | Screw | Notes |
|---|---|---|---|
| Arduino to floor standoffs | 4 | M3 x 8 | |
| Camera cradle to floor | 2 | M3 x 10 or 12, countersunk | From under the floor |
| Pan servo to base bridges | 4 | M3 x 8 | Up through the servo tabs |
| Horn column to turntable | 4 | M3 x 12, countersunk | Down from the top of the turntable |
| Tilt servo to right upright | 4 | M3 x 8 | Through the servo tabs |
| Speaker holder to cradle | 2 | M3 x 10 or 12 | Into the cradle's front edge |
| Cradle to skull | 2 | M3 x 12 to 16, with washers | Through the long slots |
| Floor to shell | 4 | M3 x 12 to 16, countersunk | Into the corner posts |
| PVC socket to floor, optional | 4 | M3 x 10 or 12 | Plus one through the side hole to pin the pipe |
| Jaw servo to cradle | 2 | The small screws supplied with the MG90S | |
| Tilt pivot | 1 | M5 x 50 bolt, 2 washers, nylon lock nut | |

That is 26 M3 screws, or 31 with the PVC socket.

## Stage 1: test everything on the bench

Do this before any part is mounted. A servo that is centered now saves taking the neck
apart later.

1. Upload the firmware to the Arduino. The README covers this in section 5.
2. Wire the three servos, the two eye jewels and the power supply on the bench,
   following the [wiring diagram](wiring.svg). Leave the horns off the servos.
3. Run `python calibrate.py servos` from the `software` folder.
4. For each servo, pick it with `0`, `1` or `2` and press `c` to center it.
5. Mark the pan and tilt servo shafts with a dot of paint so you can see the center
   position later.
6. Run `python calibrate.py eyes` and check that both jewels light.
7. Wire the amp and speaker, then run `python calibrate.py say "Howdy."` and check for
   sound.
8. Unplug everything. Keep the servos at their centered positions.

## Stage 2: prepare the skull

1. Lift off the skull cap. It is held by magnets and pegs, so pull straight up.
2. Unhook the jaw spring. The servo drives the jaw now. If the jaw later flops too
   freely, fit a much lighter rubber band in the spring's place.
3. Epoxy one `jaw_tab` to the inside of the chin. Center it, with the upright fin
   pointing back toward the throat. The grooved face is the glue face.
4. Press each LED jewel into an `eye_holder`, with the wires leaving through the slot in
   the back.
5. Clip an `eye_diffuser` onto the front of each holder.
6. Chain the jewels: the first jewel's DOUT goes to the second jewel's DIN. Join the 5V
   pads together and the GND pads together.
7. Epoxy the holders inside the eye sockets, working from inside the cranium.
8. Route the three eye wires down through the large hole in the skull base.
9. Optional: brush raw umber acrylic onto the skull and wipe it off. It leaves old bone
   color in the cracks.

Let the epoxy cure fully before hanging any weight on the jaw tab.

## Stage 3: build the neck

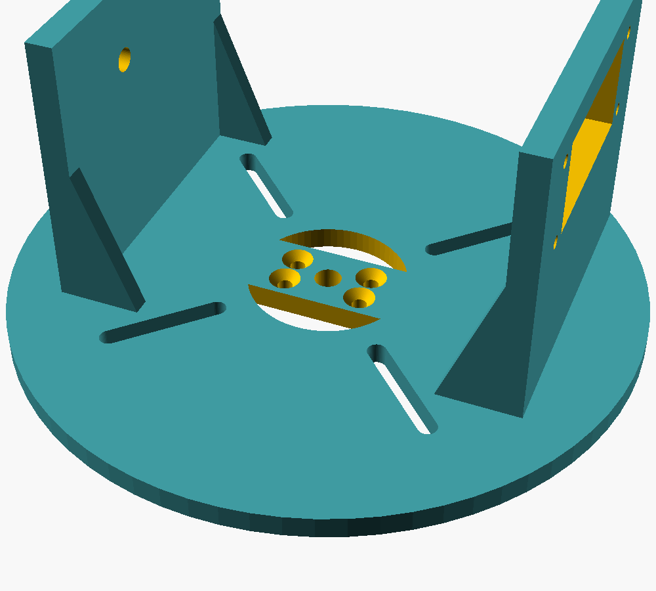
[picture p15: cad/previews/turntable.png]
The turntable


The `horn_column` has two flat sides. The wires from the head run down past those
flats, so nothing may stick out beyond them.

1. Trim two opposite sides off the pan servo's round disc horn until it is 17 mm wide,
   the same as the column. The horn is 20.5 mm across, so that is a little under 2 mm
   off each side. Side cutters and a file will do it. An untrimmed horn blocks
   the wires.
2. Screw the horn to the bottom of the column, with its trimmed sides in line with the
   flats. The bottom is the end with the slots and the wide recess. The two slots that
   run along the column are full length. The four diagonal ones are short.
3. Set the column under the center of the `turntable`, flats in line with the two
   curved openings, and fix it with four countersunk M3 screws from above.
4. Fasten the lazy susan's top plate to the underside of the turntable, through the
   diagonal slots.
5. Fasten the lazy susan's bottom plate to the top of the `base_shell`, through its
   diagonal slots. The column drops through the center opening.
6. Spin the turntable by hand. It must turn freely with no rubbing on the column.
7. Look down through each curved opening. You should see straight into the base.

Steps 4 and 5 need fasteners that the README does not list. See
[Open questions](#open-questions).

### Fit the pan servo

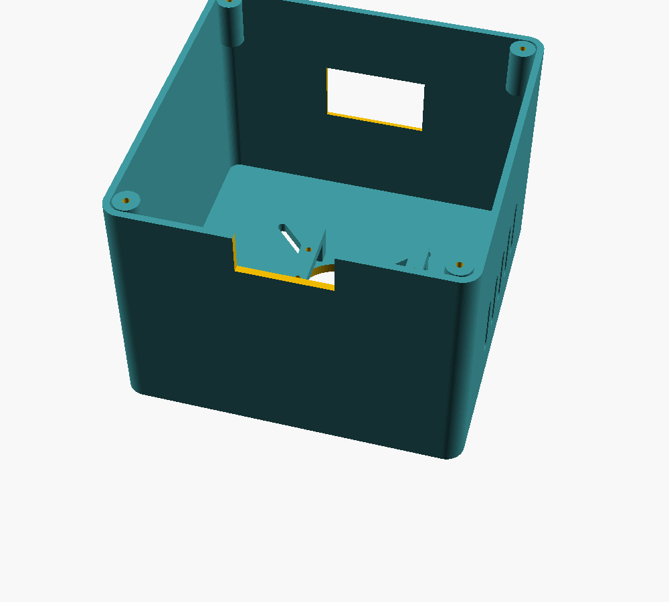
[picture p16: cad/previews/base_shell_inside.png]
Inside the base shell


8. Turn the shell upside down. The two bars near the center are the servo bridges.
9. Check that the pan servo is still centered and that the turntable uprights sit
   square to the front of the base.
10. Lower the servo between the bridges, shaft first, and press the shaft into the horn.
11. Screw the servo tabs to the bridges with four M3 x 8 screws.
12. Turn the shell upright. Put a screwdriver down the hole in the middle of the
    turntable and fit the horn screw into the servo shaft.

Do step 12 now. The skull cradle covers that hole later.

## Stage 4: build the tilt yoke

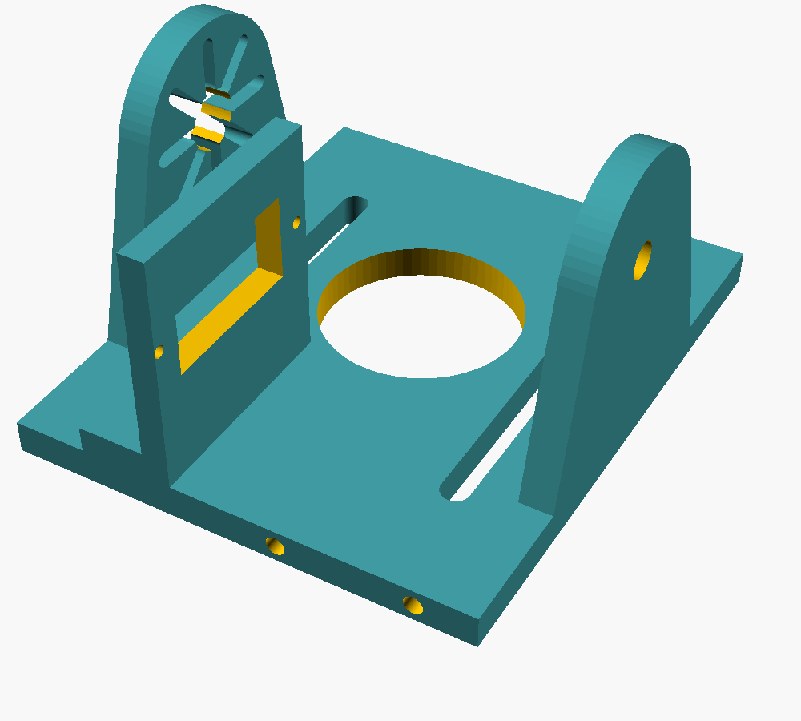
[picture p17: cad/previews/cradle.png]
The skull cradle, printed side up


1. Push the tilt servo into the cutout in the right upright, from the outside. The
   servo body stays outside and the shaft points inward.
2. Fix it with four M3 x 8 screws through the tabs.
3. Mount the MG90S jaw servo in the small plate that hangs under the front of the
   `cradle`, using the screws supplied with the servo. The shaft sits forward and low.
4. Fit the speaker into the `speaker_holder` and hold it in with zip ties through the
   three notches.
5. Screw the holder to the front edge of the cradle with two M3 screws, with the
   speaker facing forward.
6. Screw a servo horn to the cradle arm that has the radial slots. This arm goes on the
   right.
7. With the tilt servo centered, hold the cradle platform level and press that horn
   onto the tilt servo shaft. Fit the horn screw.
8. On the left, pass the M5 bolt through the upright, then the `pivot_spacer`, then the
   cradle arm. Use a washer under the bolt head and another under the nut.
9. Tighten the lock nut until the play is gone, then back it off a little. The cradle
   must swing freely.

## Stage 5: mount and balance the skull

1. Set the skull on the cradle platform, with the large hole in the skull base over
   the large hole in the platform.
2. Drive two M3 screws with washers up through the long slots into the skull base.
   **Leave them loose.**
3. Relax the tilt servo. Either unplug it, or send the relax command from the control
   page.
4. Slide the skull forward or back in the slots until it barely tips either way.
5. Tighten the two screws.

A balanced head is what lets the tilt servo hold it all day without buzzing or
overheating.

### Connect the jaw

6. Bend a Z into one end of the 1.5 mm steel wire and hook it into the jaw tab. The tab
   has two holes, which give two amounts of travel.
7. Set the jaw servo to its closed position.
8. Hold the jaw shut and cut the wire to length so the other end reaches the servo horn.
9. Hook the wire into the horn and fit the horn to the servo.
10. Move the jaw by hand through its full travel. Nothing should bind or scrape.

## Stage 6: fit out the base

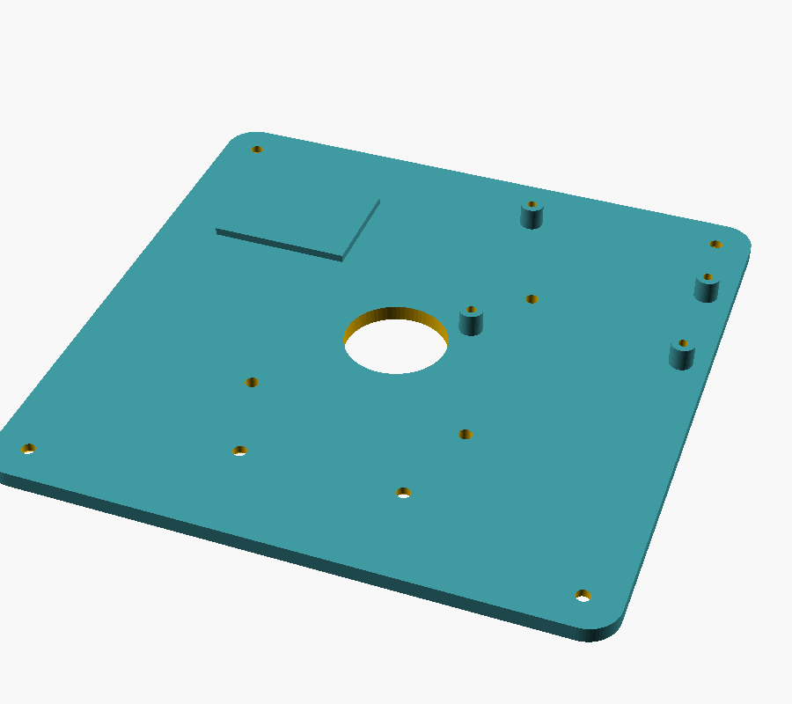
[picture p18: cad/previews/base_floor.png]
The base floor


1. Screw the Arduino to the four standoffs on the `base_floor`.
2. Stick the amp to the raised pad with double-sided foam tape.
3. Screw the `camera_cradle` to the floor from underneath with two countersunk M3
   screws. It sits just behind the window.
4. Strap the camera to the cradle shelf with zip ties through the two slots. The lens
   should sit right against the window.
5. Stretch the grille cloth over the window from outside and press the `grille_frame`
   in to clamp it.

## Stage 7: route the cables and close up

1. Gather the jaw servo, eye and speaker wires. Feed them down through the hole in the
   cradle platform.
2. Continue down through the two curved openings in the turntable, one either side of
   the horn column. Each is about 9 mm deep and 31 mm wide, which takes a servo plug.
   Split the wires between the two sides.
3. Leave a loose loop above the turntable so the head can turn 60 degrees each way
   without pulling.
4. Turn the head by hand to both limits and check that no wire goes tight.
5. Connect everything by the [wiring diagram](wiring.svg). Fit the 1000 µF capacitor
   across the power rail with its stripe to the negative side.
6. Run the power and USB cables out through the notch at the bottom rear of the shell.
7. Screw the floor to the shell with four countersunk M3 screws.
8. Optional: screw the `pvc_socket` under the floor and stand the base on a 2 inch PVC
   pipe.

## Stage 8: first power up

1. Plug in the servo supply, then the Arduino's USB cable.
2. Run `python calibrate.py servos` and find the real limits of each servo. Start with
   small steps. Stop as soon as anything touches.
3. Put the numbers in the calibration block at the top of the sketch and upload again.
4. Carry on with section 6 of the README for the eyes, voice, microphone and gaze.

## Open questions

These came up while writing this guide from the CAD source. Settle them on real parts
before gluing or closing anything.

**1. The cable path is fixed in the CAD, but not yet tried on printed parts.**
The first design had a fully round horn column that filled the bearing's center
opening and left a gap of about 2 mm. The column now has two flat sides, and the
turntable has an opening beside each one. A clearance test in OpenSCAD passes a servo
plug straight down either side. Three things still depend on your parts: the bearing's
opening must really be 35.3 mm, the horn must be trimmed, and the wires must not rub
hard on the column when the head turns.

**2. The lazy susan has no listed fasteners.**
The slots in the turntable and the base top are 4.2 mm wide and go straight through,
so self-tapping screws have nothing to bite. The bearing needs about eight short
machine screws with nuts and washers, M3 or M4 depending on the holes in its plates.
These are now noted in the parts list.

**3. Horn screws are not specified.**
The radial slots that take the horn screws are 2.4 mm wide and 8 mm deep. Use screws
that fit the holes in your horns and grip those slots.

**4. Reaching the lower bearing screws.**
Once the top plate is on the turntable, the bottom plate's screws are hidden. Most
bearings of this type have an access hole in the top plate. If yours does not, fix
the bottom plate to the base first.

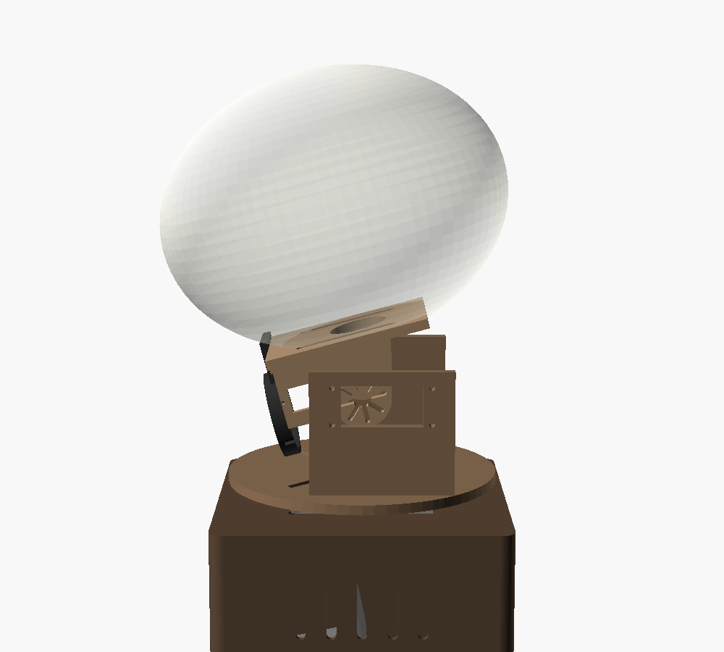
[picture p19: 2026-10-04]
cad/previews/assembly_side_tilted.png

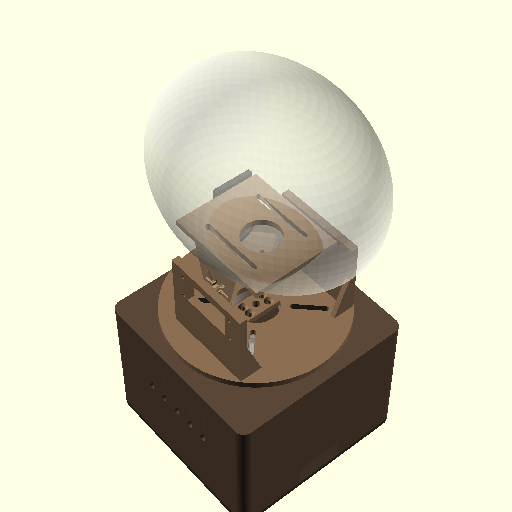
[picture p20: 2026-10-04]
cad/previews/assembly.png

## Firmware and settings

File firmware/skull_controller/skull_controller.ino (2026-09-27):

/*
  Talking skull controller: jaw + neck pan/tilt servos and WS2812 eyes.
  Board: Arduino Uno / Nano.   Libraries: Servo (built in), Adafruit NeoPixel.

  Serial 115200, newline-terminated commands from the Mac:
    J<0-100>          jaw open percent (fast, follows speech)
    L<pan>,<tilt>     look target, -100..100 percent of calibrated range (smoothed)
    E<mode>           eyes: 0 off, 1 idle, 2 alert, 3 talk, 4 listen
    C<r>,<g>,<b>      eye color
    H                 home: center head, close jaw
    X                 relax: detach servos until H (quiet, no holding torque)
    R<ch>,<us>        raw pulse for calibration, ch: 0 jaw, 1 pan, 2 tilt
    S                 status

  Safety: if the Mac goes quiet for WATCHDOG_MS, the head drifts to center
  and the jaw closes. All positions are clamped to the calibrated limits.
*/

#include <Servo.h>
#include <Adafruit_NeoPixel.h>

// ---------- pins ----------
const uint8_t PIN_JAW  = 9;
const uint8_t PIN_PAN  = 10;
const uint8_t PIN_TILT = 11;
const uint8_t PIN_EYES = 6;     // 330 ohm resistor in series to the first jewel's DIN
const uint8_t NUM_EYE_LEDS = 14; // two 7-LED jewels chained

// ---------- calibration (microseconds), find these with calibrate.py ----------
// Jaw: closed and fully open. Swap the numbers if the jaw moves backwards.
const int JAW_CLOSED_US = 1500;
const int JAW_OPEN_US   = 1150;
// Pan: center, and the pulse at +100% (turn to the skull's left from the viewer).
const int PAN_CENTER_US = 1500;
const int PAN_SPAN_US   = 500;   // +/- from center at 100%
// Tilt: center (looking level), span at +100% (looking up).
const int TILT_CENTER_US = 1500;
const int TILT_SPAN_US   = -250; // negative flips direction
// Hard limits, never exceeded even by R commands.
const int US_MIN = 700, US_MAX = 2300;

// ---------- motion feel ----------
const float PAN_MAX_SPEED  = 0.9;   // max percent change per 10 ms tick
const float TILT_MAX_SPEED = 0.6;
const float LOOK_SMOOTHING = 0.10;  // 0..1, lower = lazier head
const uint32_t WATCHDOG_MS = 3000;
const uint32_t JAW_TIMEOUT_MS = 400;
const uint8_t EYE_MAX_BRIGHTNESS = 110; // keep current and glare down

Servo jaw, pan, tilt;
Adafruit_NeoPixel eyes(NUM_EYE_LEDS, PIN_EYES, NEO_GRB + NEO_KHZ800);

float panPos = 0, tiltPos = 0, panTarget = 0, tiltTarget = 0, panVel = 0, tiltVel = 0;
int jawPct = 0;
uint8_t eyeMode = 1;
uint8_t eyeR = 255, eyeG = 32, eyeB = 0;
uint32_t lastHost = 0, lastJaw = 0, lastTick = 0, lastEye = 0;
bool attached = false;
bool relaxed = false;   // set by X, cleared by H or R

char buf[40];
uint8_t bufLen = 0;

int clampUs(long us) { return (int)constrain(us, US_MIN, US_MAX); }

void attachAll() {
  if (attached) return;
  jaw.attach(PIN_JAW);
  pan.attach(PIN_PAN);
  tilt.attach(PIN_TILT);
  attached = true;
}

void detachAll() {
  jaw.detach(); pan.detach(); tilt.detach();
  attached = false;
}

void writeServos() {
  if (!attached) return;
  jaw.writeMicroseconds(clampUs(JAW_CLOSED_US + (long)(JAW_OPEN_US - JAW_CLOSED_US) * jawPct / 100));
  pan.writeMicroseconds(clampUs(PAN_CENTER_US + (long)(PAN_SPAN_US * panPos / 100.0)));
  tilt.writeMicroseconds(clampUs(TILT_CENTER_US + (long)(TILT_SPAN_US * tiltPos / 100.0)));
}

// Critically damped-ish follow with a speed cap: smooth starts and stops.
void stepAxis(float &pos, float &vel, float target, float maxSpeed) {
  float desired = (target - pos) * LOOK_SMOOTHING;
  vel += (desired - vel) * 0.25;
  vel = constrain(vel, -maxSpeed, maxSpeed);
  pos += vel;
}

void updateEyes(uint32_t now) {
  if (now - lastEye < 20) return;
  lastEye = now;
  float level;
  switch (eyeMode) {
    case 0: level = 0; break;
    case 1: level = 0.18 + 0.12 * sin(now / 900.0); break;             // slow breathing
    case 2: level = 0.55; break;                                        // alert
    case 3: level = 0.35 + 0.65 * jawPct / 100.0                        // talk: flare with jaw
                    + 0.05 * sin(now / 37.0); break;
    case 4: level = 0.40 + 0.15 * sin(now / 250.0); break;              // listening pulse
    default: level = 0.3;
  }
  level = constrain(level, 0, 1);
  // Small per-LED flicker so the eyes feel like embers, not bulbs.
  for (uint8_t i = 0; i < NUM_EYE_LEDS; i++) {
    float f = level * (0.85 + 0.15 * ((i * 73 + now / 60) % 17) / 16.0);
    if (i % 7 == 0) f = min(1.0, f * 1.2);  // jewel center LED a bit hotter
    uint8_t k = (uint8_t)(f * EYE_MAX_BRIGHTNESS);
    eyes.setPixelColor(i, eyes.Color((uint16_t)eyeR * k / 255, (uint16_t)eyeG * k / 255,
                                     (uint16_t)eyeB * k / 255));
  }
  eyes.show();
}

void status() {
  Serial.print(F("OK pan=")); Serial.print(panPos, 0);
  Serial.print(F(" tilt=")); Serial.print(tiltPos, 0);
  Serial.print(F(" jaw=")); Serial.print(jawPct);
  Serial.print(F(" eyes=")); Serial.print(eyeMode);
  Serial.println(attached ? F(" servos=on") : F(" servos=off"));
}

void handle(char *cmd) {
  char c = cmd[0];
  char *arg = cmd + 1;
  lastHost = millis();
  switch (c) {
    case 'J':
      if (!relaxed) attachAll();
      jawPct = constrain(atoi(arg), 0, 100);
      lastJaw = millis();
      break;
    case 'L': {
      if (!relaxed) attachAll();
      char *comma = strchr(arg, ',');
      panTarget = constrain(atoi(arg), -100, 100);
      if (comma) tiltTarget = constrain(atoi(comma + 1), -100, 100);
      break;
    }
    case 'E': eyeMode = constrain(atoi(arg), 0, 4); break;
    case 'C': {
      int r = 0, g = 0, b = 0;
      sscanf(arg, "%d,%d,%d", &r, &g, &b);
      eyeR = constrain(r, 0, 255); eyeG = constrain(g, 0, 255); eyeB = constrain(b, 0, 255);
      break;
    }
    case 'H':
      relaxed = false;
      attachAll();
      panTarget = tiltTarget = 0; jawPct = 0;
      break;
    case 'X':
      relaxed = true;
      detachAll();
      break;
    case 'R': {
      int ch = 0, us = 1500;
      sscanf(arg, "%d,%d", &ch, &us);
      relaxed = false;
      attachAll();
      us = clampUs(us);
      if (ch == 0) jaw.writeMicroseconds(us);
      if (ch == 1) pan.writeMicroseconds(us);
      if (ch == 2) tilt.writeMicroseconds(us);
      Serial.print(F("RAW ")); Serial.print(ch); Serial.print(' '); Serial.println(us);
      lastTick = millis() + 5000;  // hold the raw pose for 5 s before normal motion resumes
      return;
    }
    case 'S': status(); return;
    default: break;
  }
}

void setup() {
  Serial.begin(115200);
  eyes.begin();
  eyes.clear();
  eyes.show();
  attachAll();
  writeServos();
  lastHost = millis();
  Serial.println(F("SKULL READY"));
}

void loop() {
  while (Serial.available()) {
    char ch = Serial.read();
    if (ch == '\n' || ch == '\r') {
      if (bufLen) { buf[bufLen] = 0; handle(buf); bufLen = 0; }
    } else if (bufLen < sizeof(buf) - 1) {
      buf[bufLen++] = ch;
    }
  }

  uint32_t now = millis();
  if ((int32_t)(now - lastTick) >= 10) {
    lastTick = now;
    if (now - lastHost > WATCHDOG_MS) { panTarget = 0; tiltTarget = 0; jawPct = 0; }
    if (now - lastJaw > JAW_TIMEOUT_MS) jawPct = 0;
    stepAxis(panPos, panVel, panTarget, PAN_MAX_SPEED);
    stepAxis(tiltPos, tiltVel, tiltTarget, TILT_MAX_SPEED);
    writeServos();
  }
  updateEyes(now);
}

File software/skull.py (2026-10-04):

#!/usr/bin/env python3
"""
Silas Marrow, the talking skull of the Elephant Corral.

    python skull.py --list-cameras          find the Anker camera index
    python skull.py --list-audio            find speaker and mic device names
    python skull.py --show --no-skull       test vision + voice without the Arduino
    python skull.py --show                  full run with a preview window
    python skull.py                         headless (use the phone page)
    python skull.py --virtual               on-screen 3D skull instead of the Arduino,
                                            using this computer's camera, mic and speakers

Control page: http://<mac-mini>.local:8090      3D skull: .../skull
"""

from __future__ import annotations

import argparse
import json
import logging
import math
import os
import random
import subprocess
import threading
import time
import webbrowser
from collections import deque
from http.server import BaseHTTPRequestHandler, ThreadingHTTPServer
from pathlib import Path
from urllib.parse import parse_qs, unquote, urlencode, urlparse

import cv2
from dotenv import load_dotenv

from hardware import Skull
from virtual import FirmwareSim
from faces import MAX_SAMPLES, FaceMemory
from vision import Camera, Tracker, camera_names, draw_overlay, head_to_look, pick_target

HERE = Path(__file__).resolve().parent
WEB = HERE / "web"
log = logging.getLogger("skull")

STATIC_TYPES = {
    ".html": "text/html; charset=utf-8",
    ".js": "text/javascript; charset=utf-8",
    ".css": "text/css; charset=utf-8",
    ".json": "application/json",
    ".txt": "text/plain; charset=utf-8",
    ".glb": "model/gltf-binary",
    ".png": "image/png",
    ".jpg": "image/jpeg",
}
CHROME = Path("/Applications/Google Chrome.app/Contents/MacOS/Google Chrome")

EYES_OFF, EYES_IDLE, EYES_ALERT, EYES_TALK, EYES_LISTEN = range(5)

CANNED = [
    "Well, well. Another soul wanders into the Elephant Corral.",
    "Wipe your boots. This floor has seen better mud than yours.",
    "Welcome, stranger. The faro table is closed, but the coffee is just as dangerous.",
]

LINGER_NOTE = ("You already greeted this person earlier today. They have stopped and are "
               "looking at you again, so do not welcome them as a newcomer. Needle them "
               "for coming back.")


def load_config(path: Path) -> dict:
    return json.loads(path.read_text())


def apply_virtual_overrides(cfg: dict):
    """--virtual: lay the virtual.camera/ears/voice/gaze settings over the main ones."""
    for section in ("camera", "ears", "voice", "gaze"):
        cfg[section].update(cfg.get("virtual", {}).get(section, {}))


def viewer_config(cfg: dict) -> dict:
    v = cfg.get("virtual", {})
    model = v.get("model") or ""
    return {
        "pan_range_deg": cfg["gaze"]["pan_range_deg"],
        "tilt_range_deg": cfg["gaze"]["tilt_range_deg"],
        "jaw_open_deg": v.get("jaw_open_deg", 24),
        "invert_pan": v.get("invert_pan", False),
        "invert_tilt": v.get("invert_tilt", False),
        # A sculpted model in web/ replaces the built-in skull. None if there is none.
        "model": model if model and (WEB / model).is_file() else None,
        "camera_inset": v.get("camera_inset", True),
        "subtitles": v.get("subtitles", True),
    }


def open_viewer(url: str):
    """Open the 3D skull in its own window: Chrome app mode if we can, else a tab."""
    try:
        if CHROME.exists():
            subprocess.Popen([str(CHROME), f"--app={url}"], stdout=subprocess.DEVNULL,
                             stderr=subprocess.DEVNULL, start_new_session=True)
            return
    except OSError as e:
        log.warning("Could not start Chrome (%s), using the default browser", e)
    webbrowser.open(url)


class Director:
    """Owns the skull's behavior: who to look at, when to talk, when to listen."""

    def __init__(self, cfg: dict, skull: Skull, brain, mouth, ears, faces=None):
        self.cfg = cfg
        self.skull, self.brain, self.mouth, self.ears = skull, brain, mouth, ears
        self.faces = faces                  # FaceMemory, or None to go by track ID alone
        self._face_try = 0.0
        self._watch = None                  # what the face memory knows about the target
        b = cfg["behavior"]
        self.armed = b.get("start_armed", False)
        self.conversation = b.get("conversation", True) and ears is not None
        self.state = "idle"
        self.lock = threading.Lock()

        # shared with the vision loop
        self.frame = None
        self.people = []
        self.target = None
        self.target_since = 0.0
        self.last_seen = 0.0
        self.jpeg = None

        # bookkeeping
        self.last_greet = -1e9
        self.greet_times: deque[float] = deque()
        self.greeted_ids: dict[int, float] = {}
        self.last_ambient = time.monotonic()
        self.last_said = ""
        self.last_heard = ""
        self.said_n = self.heard_n = 0      # lets the 3D page spot a repeated line
        self.events: deque[str] = deque(maxlen=60)
        self._eyes = None
        self._manual: deque[tuple[str, str]] = deque()
        self._cancel = threading.Event()
        self._hush = threading.Event()      # stops a pretend (no voice) line

    # ---- helpers -------------------------------------------------------
    def event(self, msg: str):
        log.info(msg)
        with self.lock:
            self.events.appendleft(time.strftime("%H:%M:%S  ") + msg)

    def eyes(self, mode: int):
        if mode != self._eyes:
            self._eyes = mode
            self.skull.eyes(mode)

    def say(self, text: str) -> bool:
        self.last_said = text
        self.said_n += 1
        self.event(f"SAY: {text}")
        if self.mouth is None:
            return self._pretend(text)
        return self.mouth.say(text)

    def _pretend(self, text: str) -> bool:
        """No voice: move the jaw for about as long as the line would take."""
        self._hush.clear()
        self.eyes(EYES_TALK)
        t0 = time.monotonic()
        length = min(6.0, 0.35 * len(text.split()))
        try:
            while (t := time.monotonic() - t0) < length:
                if self._hush.is_set():
                    return False
                syllable = abs(math.sin(t * math.pi * 4.2))
                phrase = 0.5 + 0.5 * math.sin(t * 1.9 + 1.0) ** 2
                self.skull.jaw(100 * syllable * phrase)
                time.sleep(0.02)
            return True
        finally:
            self.skull.jaw(0)
            self.eyes(EYES_ALERT)

    def person_here(self) -> bool:
        return time.monotonic() - self.last_seen < self.cfg["behavior"]["gone_after_s"]

    def active_hours(self) -> bool:
        start, end = self.cfg["behavior"].get("active_hours", [0, 24])
        return start <= time.localtime().tm_hour < end
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

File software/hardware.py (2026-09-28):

"""
Serial link to the skull's Arduino (jaw, neck pan/tilt, eye LEDs).

A background thread streams the latest jaw and look targets at a fixed rate,
so the audio and vision threads only ever set numbers and never block on USB.
Protocol (newline terminated, see firmware/skull_controller.ino):
    J<0-100>            jaw open percent
    L<pan>,<tilt>       look target, each -100..100 percent of calibrated range
    E<mode>             eyes: 0 off, 1 idle, 2 alert, 3 talk, 4 listen
    C<r>,<g>,<b>        eye color 0-255
    H                   home (center, jaw closed)
    X                   relax (detach servos)
    S                   status

Every line is also handed to an optional FirmwareSim (virtual.py), which drives
the on-screen 3D skull. With dry_run it is the only receiver.
"""

from __future__ import annotations

import logging
import threading
import time

import serial

log = logging.getLogger("skull.hw")


class Skull:
    def __init__(self, port: str, baud: int = 115200, dry_run: bool = False,
                 rate_hz: float = 50.0, sim=None):
        self.port = port
        self.baud = baud
        self.dry_run = dry_run
        self.sim = sim
        self.period = 1.0 / rate_hz
        self.connected = dry_run
        self.status_line = (("virtual" if sim else "dry run") if dry_run
                            else "disconnected")

        self._lock = threading.Lock()
        self._jaw = 0
        self._look = (0, 0)
        self._sent_jaw = None
        self._sent_look = None
        self._last_look_sent = 0.0
        self._last_jaw_sent = 0.0
        self._pending: list[str] = []
        self._ser = None

    # ---- targets set by other threads ---------------------------------
    def jaw(self, percent: float):
        self._jaw = int(max(0, min(100, percent)))

    def look(self, pan: float, tilt: float):
        self._look = (int(max(-100, min(100, pan))), int(max(-100, min(100, tilt))))

    def eyes(self, mode: int):
        self.command(f"E{int(mode)}")

    def eye_color(self, r: int, g: int, b: int):
        self.command(f"C{int(r)},{int(g)},{int(b)}")

    def home(self):
        self._jaw = 0
        self._look = (0, 0)
        self.command("H")

    def relax(self):
        self.command("X")

    def command(self, cmd: str):
        with self._lock:
            self._pending.append(cmd)

    # ---- serial thread --------------------------------------------------
    def start(self):
        threading.Thread(target=self._run, daemon=True, name="skull-serial").start()

    def _run(self):
        while True:
            if self.dry_run:
                self._pump(lambda line: log.debug("(dry) %s", line))
                continue
            try:
                with serial.Serial(self.port, self.baud, timeout=0) as ser:
                    time.sleep(2.0)  # Arduino resets when the port opens
                    ser.reset_input_buffer()
                    self._ser = ser
                    self.connected = True
                    self._sent_jaw = self._sent_look = None
                    log.info("Skull connected on %s", self.port)
                    buf = b""
                    while True:
                        self._pump(lambda line: ser.write((line + "\n").encode()))
                        data = ser.read(256)
                        if data:
                            buf += data
                            while b"\n" in buf:
                                line, buf = buf.split(b"\n", 1)
                                text = line.decode(errors="replace").strip()
                                if text:
                                    self.status_line = text
                                    log.debug("skull: %s", text)
            except (serial.SerialException, OSError) as e:
                if self.connected:
                    log.warning("Skull serial lost (%s), retrying", e)
                self.connected = False
                self._ser = None
                self.status_line = "disconnected"
                time.sleep(3)

    def _pump(self, send):
        start = time.monotonic()
        sim = self.sim

        def write(line):
            send(line)
            if sim is not None:
                sim.handle(line)

        with self._lock:
            pending, self._pending = self._pending, []
        for cmd in pending:
            write(cmd)
        jaw = self._jaw
        # Re-send an open jaw every 100 ms; the firmware closes it if we go quiet.
        if jaw != self._sent_jaw or (jaw > 0 and start - self._last_jaw_sent > 0.1):
            write(f"J{jaw}")
            self._sent_jaw = jaw
            self._last_jaw_sent = start
        look = self._look
        # Re-send the look target at least every 0.5 s so the firmware
        # watchdog knows the host is alive.
        if look != self._sent_look or start - self._last_look_sent > 0.5:
            write(f"L{look[0]},{look[1]}")
            self._sent_look = look
            self._last_look_sent = start
        time.sleep(max(0.0, self.period - (time.monotonic() - start)))

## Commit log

2026-09-27 Initial version of the talking skull
    Python software (vision, Claude, ElevenLabs voice, phone control page),
    Arduino firmware for the jaw/neck servos and eye LEDs, and parametric
    OpenSCAD parts with exported STLs.
    [base_floor.stl, base_shell.stl, camera_cradle.stl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]
2026-09-28 Add virtual 3D skull that stands in for the Arduino
    python skull.py --virtual shows an animated skull on screen and runs the
    full behavior with this computer's camera, microphone and speakers.
    - virtual.py: software twin of the sketch. It takes the same serial
    commands and reproduces head smoothing, the jaw timeout and the
    host watchdog.
    - hardware.py: every serial line is also handed to the twin, so /skull
    is a live view next to the real hardware too.
    - skull.py: --virtual flag, /skull page, /web static files, /api/pose
    event stream, and a moving jaw when running with --no-voice.
    - web/: three.js viewer with a generated skull. A sculpted
    web/skull.glb replaces it when present. th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
    [hardware.py, skull.py, virtual.py]
2026-09-28 Fix the neck cable path and add build docs
    Flatten the horn column to column_w and replace the turntable's round
    cable holes with openings beside the column's flats, so the wires from
    the head can drop through the lazy susan. The column screws move to
    four positions between the horn slots (col_screw_a). Re-export the
    turntable and horn_column STLs and the turntable preview.
    Add docs/parts.md, docs/wiring.svg and docs/assembly.md, and link them
    from the README. Update the README wiring and assembly steps and
    CLAUDE.md to match.
    [horn_column.stl, skull_parts.scad, turntable.stl]
2026-10-04 Update dimensions for lazy susan and servos
    [skull_parts.scad]
2026-10-04 Regenerate STLs and previews for updated dimensions
    [base_floor.stl, base_shell.stl, camera_cradle.stl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]
2026-10-04 Update build docs for new lazy susan, camera and horn dimensions
2026-10-04 Fix lazy susan size comment in skull_parts.scad
    [skull_parts.scad]
2026-10-04 Add print order to the README
2026-10-04 Make Silas ornery, move to Sonnet 5.5 and start armed
    Rewrite the persona to be cantankerous and joke-first. Switch the
    model to Sonnet 5.5 with thinking off so lines are not empty, raise
    max_tokens to 300, and start armed. Skip optimize_streaming_latency
    for eleven_v3, which rejects it.
    [brain.py, voice.py]
2026-10-04 Tighten persona rule against commenting on posture and expression
2026-10-04 Remember greeted faces for 4 hours and pick the camera by name
    Add faces.py: in-memory face embeddings (OpenCV YuNet + SFace) so a
    person is greeted once per 4 hours even if they leave and return.
    Someone already greeted who looks at the skull for 10 seconds gets
    another line, at most every 5 minutes.
    Pick the virtual camera by name so an iPhone Continuity Camera cannot
    take index 0. Add a subtitles setting and turn off the camera inset
    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
2026-10-13 Update assembly.md to remove obsolete print instructions
    Removed outdated instructions regarding the turntable and horn_column prints.
2026-10-20 Make the base shell and cradle print without supports
    Corner bosses fuse into the shell walls with a 45 degree taper, the pan
    servo bridges get gussets, and the rear right boss is flattened so the
    Arduino corner clears it. The cradle's jaw plate extends past the front
    edge to wall in the front screw hole, and the horn hub slots leave a
    ring around a smaller center hole so the wedges print standing up. The
    camera cradle shelf now runs under the front lip. Regenerate the three
    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
2026-10-20 Aim the camera cradle up and clear the USB-C plug
    The shelf rotated the wrong way, so the camera aimed 12 degrees down. It
    now tilts back about its front edge and aims up at faces above the base.
    The shelf moves 13 mm forward on its feet, which puts the lens about
    1 cm behind the window; the floor screw holes are unchanged. The back
    stop drops to sit under the camera's USB-C plug, set by the new
    cam_cord_z measurement. Regenerate the camera cradle STL and update the
    mounting notes in the README and assembly guide.
